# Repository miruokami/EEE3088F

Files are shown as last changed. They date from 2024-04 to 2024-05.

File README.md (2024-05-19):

# Micro-mouse Project
## Project Overview
The Micro-mouse project focuses on designing and building subassemblies for a simplified micro-mouse, a maze-solving robot. 
This project involves creating hardware components with some minor software aspects, adhering to a strict budget.

## Project Modules
### Provided Modules
Motherboard: Connects all the PCBs together, serving as the base for other modules.
Processor: A STM32xxx processor board.

### Modules to Design and Manufacture
#### Power Module:
Responsibilities: Powering the entire system, running the motors, and charging the battery.
Requirements: Fit onto the motherboard pin headers, appropriate size for the robot, includes necessary connectors (e.g., JST PH 2mm pitch for the battery, 2x8 pin header for motherboard connection).

#### Sensor Module:
Responsibilities: Detecting and sensing objects.
Requirements: Fit onto the motherboard pin headers, appropriate size for the robot, utilize hysteresis for sensing, accurately sense different maze wall configurations.

## Demonstration Procedures
### Sensing Subsystem
Preparation: Bring a PCB, code ready to flash onto the STM32F0, and populated PCB.
Setup: Flash code, connect the necessary wires, plug sensing PCB into the testing PCB.
Testing: The sensor is supplied with power, and walls will be moved in various configurations to test the sensing accuracy.

### Power Subsystem
Preparation: Bring a PCB, and 4 spare PCBs.
Setup: Plug power PCB into the testing jig.

This README provides a concise overview of the Micro-mouse project, including project modules, and demonstration procedures. 
For comprehensive guidelines, please refer to the provided project description document .

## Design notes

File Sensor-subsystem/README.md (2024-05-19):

# Robot Sensor Subsystem
## Overview
This repository contains the design, implementation, and integration details of the sensor subsystem for a robot project. The sensor subsystem is responsible for detecting obstacles in front, to the left, and to the right of the robot, providing essential information for navigation and obstacle avoidance.

## Features
Obstacle Detection: Uses IR sensors to detect obstacles in three directions: front, left, and right.
Power Management: Implements MOSFET switches to enable/disable sensors, conserving battery power when sensors are not in use.
Visual Indication: Uses LEDs on the processor board to indicate the presence of obstacles.
High Reliability: Designed with redundant ground planes, decoupling capacitors, and other failure management processes to ensure robust operation.

## System Integration
The sensor subsystem integrates with the main robot system through a 2x14 pin header connection. It interfaces with the robot's processor to provide obstacle detection data and receive power management signals.

## Power Management
To ensure efficient power usage, the subsystem employs MOSFET switches controlled by PWM signals from the processor. This allows the sensors to be powered only when needed, conserving battery life.

## Components
IR Sensors: Detect obstacles by emitting and detecting infrared light.
MOSFETs: Switch the power supply to the sensors on and off.
Microcontroller: Reads sensor data and controls MOSFETs and LEDs.
LEDs: Indicate the presence of obstacles.

## Software
The software interfaces the sensor subsystem with the rest of the robot's system, handling sensor readings, power management, and LED indications.

## Getting Started
Hardware Setup: Assemble the sensor subsystem on the PCB and connect it to the robot's processor board using the 2x14 pin header.
Software Setup: write code to the microcontroller to start interfacing with the sensors.
Testing: Use the LEDs to verify that the sensors are correctly detecting obstacles.

# License
This project is licensed under the MIT License - see the LICENSE file for details.

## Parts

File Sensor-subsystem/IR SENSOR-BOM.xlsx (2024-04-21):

ID | Designator | Footprint |  | Comment | Supplier and ref
1 | D2 | LED_D5.0mm_Horizontal_O3.81mm_Z3.0mm | 1 | IR_LED
2 | RV1 | Potentiometer_ACP_CA9-H2 | 1 | 10k
3 | D1 | LED_D5.0mm_Horizontal_O3.81mm_Z3.0mm | 1 | D_Photo
4 | JP2 | SolderJumper-2_P1.3mm_Open_TrianglePad1.0x1.5mm | 1 | Jumper_2_Open
5 | R1 | R_Axial_DIN0204_L3.6mm_D1.6mm_P2.54mm_Vertical | 1 | 10k
6 | R2 | R_Axial_DIN0204_L3.6mm_D1.6mm_P2.54mm_Vertical | 1 | 270
7 | JP1 | SolderJumper-2_P1.3mm_Bridged_RoundedPad1.0x1.5mm | 1 | Jumper_2_Bridged
8 | U1 | DFN-8-1EP_2x2mm_P0.5mm_EP1.05x1.75mm | 1 | LM358_DFN
9 | J1 | PinHeader_2x14_P2.54mm_Vertical | 1 | Conn_02x14_Male

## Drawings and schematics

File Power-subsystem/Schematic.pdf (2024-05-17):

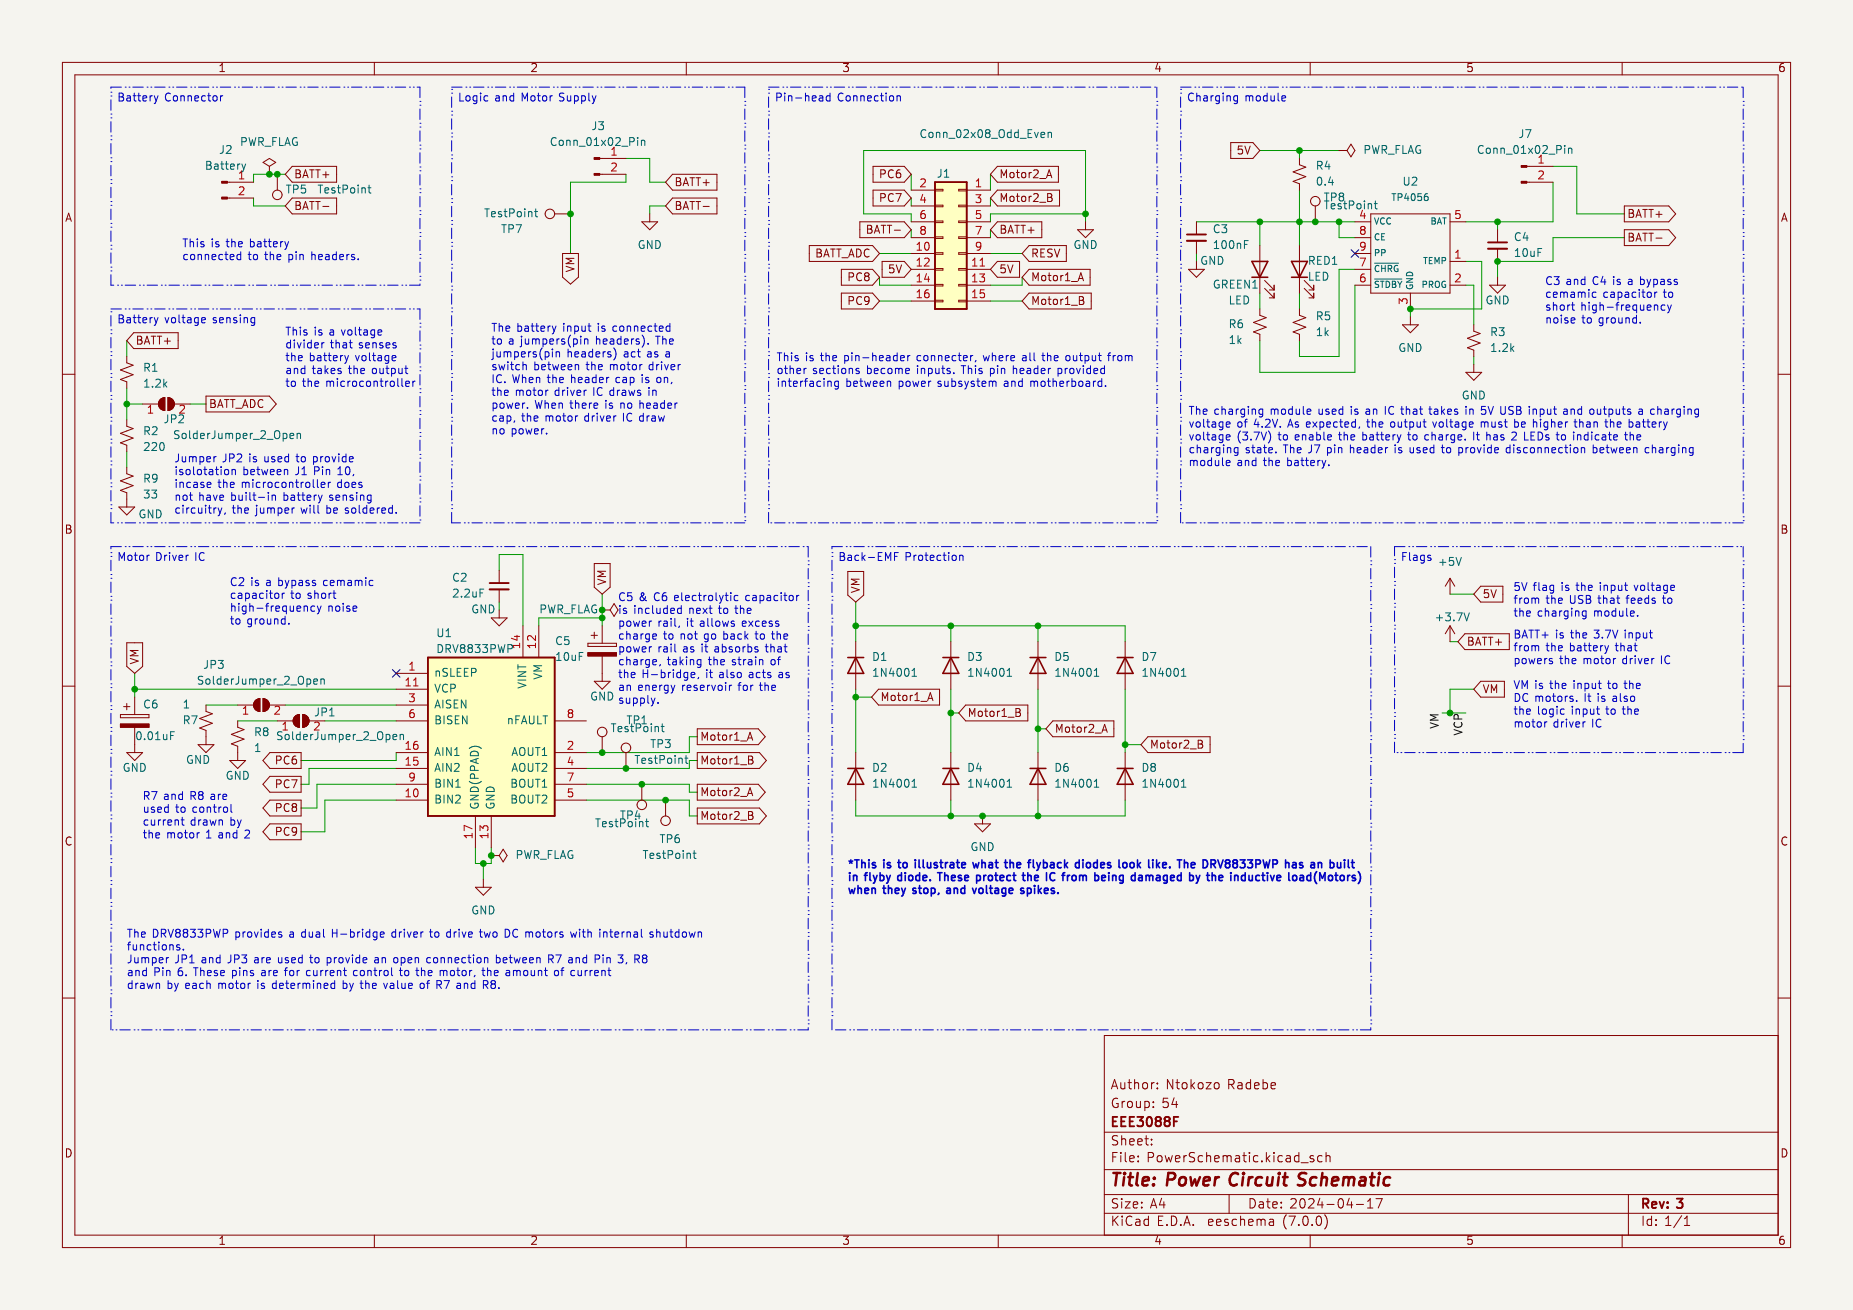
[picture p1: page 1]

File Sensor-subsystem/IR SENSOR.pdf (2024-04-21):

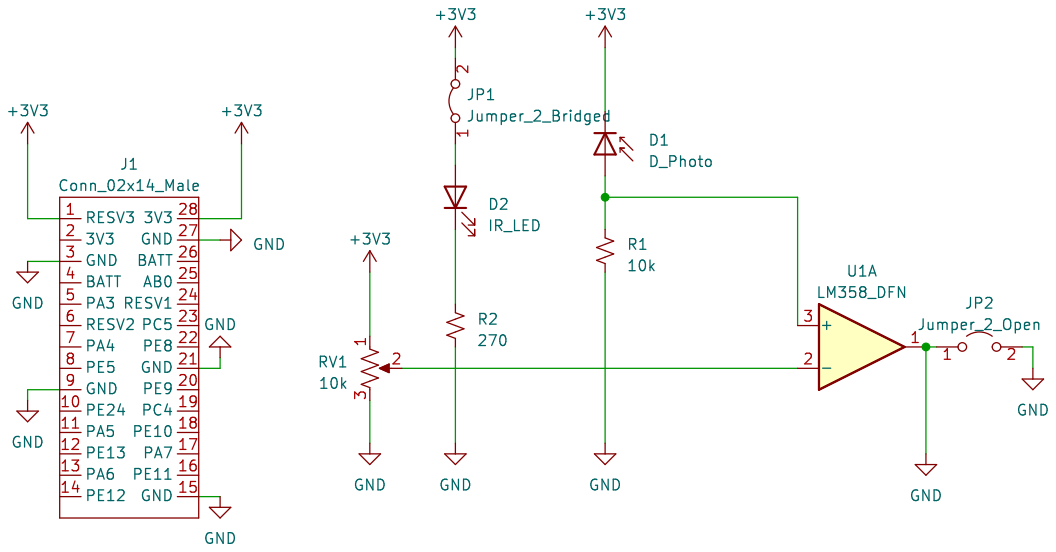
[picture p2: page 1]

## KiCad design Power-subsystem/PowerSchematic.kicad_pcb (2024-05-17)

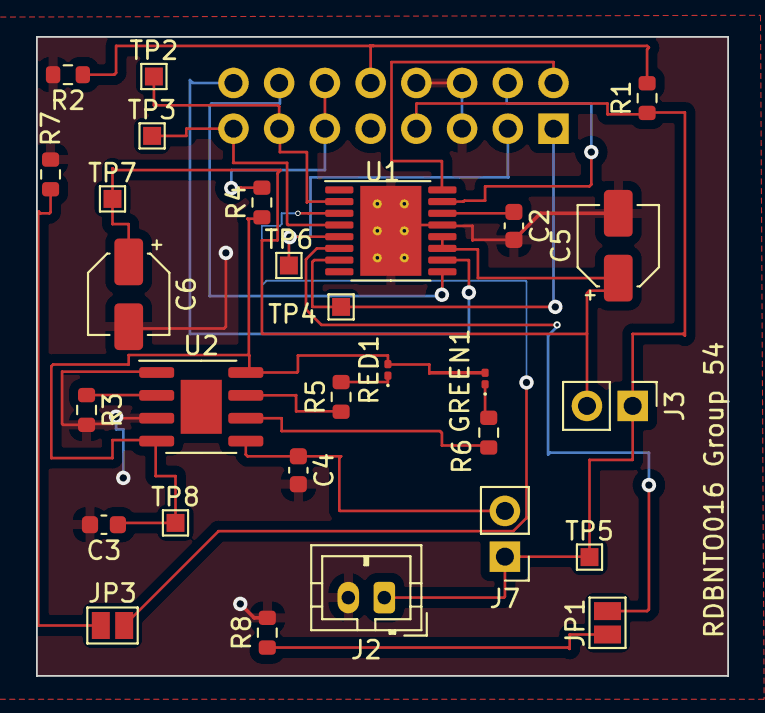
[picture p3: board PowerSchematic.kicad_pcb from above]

Board: 2 copper layers, 38.4 x 35.5 mm, 30 parts (1 on the bottom side), 25 nets.

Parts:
C2: 2.2uF; C_0603_1608Metric
C3: 100nF; C_0603_1608Metric
C4: 10uF; C_0603_1608Metric
C5: 10uF; CP_Elec_4x3
C6: 0.01uF; CP_Elec_4x3
GREEN1: LED; LED_0201_0603Metric
J1: Conn_02x08_Odd_Even; PinHeader_2x08_P2.54mm_Vertical
J2: Battery; JST_PH_B2B-PH-K_1x02_P2.00mm_Vertical
J3, J7: Conn_01x02_Pin; PinHeader_1x02_P2.54mm_Vertical
JP1, JP3: SolderJumper_2_Open; SolderJumper-2_P1.3mm_Open_Pad1.0x1.5mm
R1: 10k; R_0603_1608Metric
R2: 5k; R_0603_1608Metric
R3: 1.2k; R_0603_1608Metric
R4: 0.4; R_0603_1608Metric
R5, R6: 1k; R_0603_1608Metric
R7, R8: 1; R_0603_1608Metric
RED1: LED; LED_0201_0603Metric
TP2, TP3, TP4, TP5, TP6, TP7, TP8: TestPoint; TestPoint_Pad_1.0x1.0mm
U1: DRV8833PWP; HTSSOP-16-1EP_4.4x5mm_P0.65mm_EP3.4x5mm_Mask2.46x2.31mm_The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
U2: TP4056; SOIC-8-1EP_3.9x4.9mm_P1.27mm_EP2.29x3mm

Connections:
5V: J1.11, J1.12, R4.2
BATT+: J1.7, J2.1, J3.1, J7.1, R1.1, TP5.1
BATT-: C2.2, C3.2, C4.2, C5.2, C6.2, J1.5, J1.6, J1.8, J2.2, R2.2, R3.2, R7.2, R8.2, U1.13 (GND), U1.17 (GND(PPAD)), U2.1 (TEMP), U2.3 (GND)
BATT_ADC: J1.10, R1.2, R2.1
Motor1_A: J1.13, TP2.1, U1.2 (AOUT1)
Motor1_B: J1.15, TP3.1, U1.4 (AOUT2)
Motor2_A: J1.1, TP4.1, U1.7 (BOUT1)
Motor2_B: J1.3, TP6.1, U1.5 (BOUT2)
unnamed: C3.1, GREEN1.2 (A), R4.1, RED1.2 (A), TP8.1, U2.4 (VCC), U2.8 (CE)
unnamed: GREEN1.1 (K), R6.2
unnamed: C4.1, J7.2, U2.5 (BAT)
unnamed: JP1.1 (A), R8.1
unnamed: JP1.2 (B), U1.6 (BISEN)
unnamed: JP3.1 (A), R7.1
unnamed: JP3.2 (B), U1.3 (AISEN)
unnamed: R5.2, RED1.1 (K)
unnamed: C2.1, U1.14 (VINT)
unnamed: R3.1, U2.2 (PROG)
unnamed: R5.1, U2.7 (~CHRG)
unnamed: R6.1, U2.6 (~STDBY)
PC6: J1.2, U1.16 (AIN1)
PC7: J1.4, U1.15 (AIN2)
PC8: J1.14, U1.9 (BIN1)
PC9: J1.16, U1.10 (BIN2)
VM: C5.1, C6.1, J3.2, TP7.1, U1.11 (VCP), U1.12 (VM)

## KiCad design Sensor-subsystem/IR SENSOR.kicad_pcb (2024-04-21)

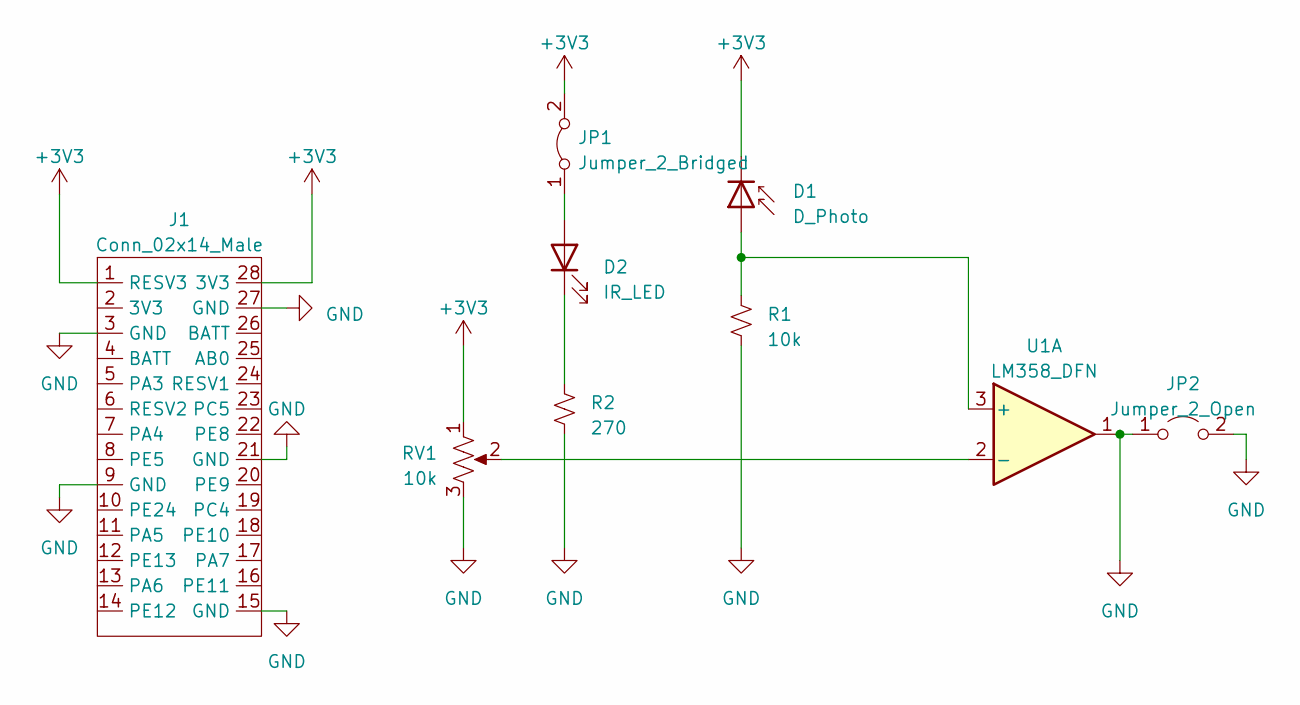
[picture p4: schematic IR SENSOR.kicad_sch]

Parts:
D1: D_Photo; LED_D5.0mm_Horizontal_O3.81mm_Z3.0mm
D2: IR_LED; LED_D5.0mm_Horizontal_O3.81mm_Z3.0mm
J1: Conn_02x14_Male; PinHeader_2x14_P2.54mm_Vertical
JP1: Jumper_2_Bridged; SolderJumper-2_P1.3mm_Bridged_RoundedPad1.0x1.5mm
JP2: Jumper_2_Open; SolderJumper-2_P1.3mm_Open_TrianglePad1.0x1.5mm
R1: 10k; R_Axial_DIN0204_L3.6mm_D1.6mm_P2.54mm_Vertical
R2: 270; R_Axial_DIN0204_L3.6mm_D1.6mm_P2.54mm_Vertical
RV1: 10k; Potentiometer_ACP_CA9-H2,5_Horizontal
U1: LM358_DFN; DFN-8-1EP_2x2mm_P0.5mm_EP1.05x1.75mm

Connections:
+3V3: D1.1 (K), J1.1 (RESV3), J1.28 (3V3), JP1.2 (B), RV1.1
GND: J1.3 (GND), J1.9 (GND), J1.15 (GND), J1.21 (GND), J1.27 (GND), JP2.1 (A), JP2.2 (B), R1.1, R2.1, RV1.3, U1.1
unnamed: D1.2 (A), R1.2, U1.3 (+)
unnamed: D2.2 (A), JP1.1 (A)
unnamed: D2.1 (K), R2.2
unnamed: RV1.2, U1.2 (-)

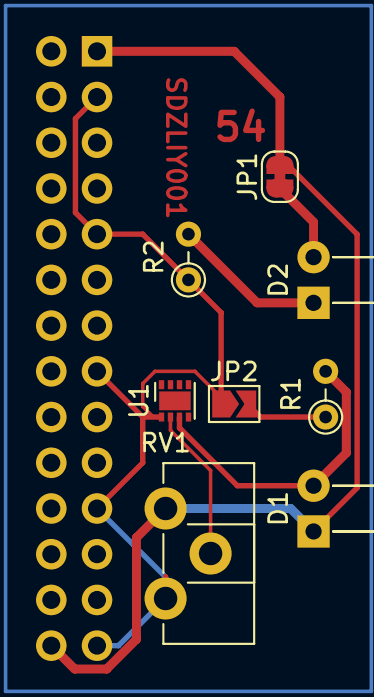
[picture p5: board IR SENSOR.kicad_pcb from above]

Board: 2 copper layers, 9 parts (1 on the bottom side), 6 nets.

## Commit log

2024-04-21 Add files via upload
    Added all necessary documents.
    [PowerSchematic.kicad_pcb, PowerSchematic.kicad_sch]
2024-05-17 Moving files to sensor foulder
    [IR SENSOR-BOM.xlsx, IR SENSOR.kicad_pcb, IR SENSOR.kicad_sch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]
2024-05-17 moving files to power foulder
    [PowerSchematic.kicad_pcb, PowerSchematic.kicad_sch]
